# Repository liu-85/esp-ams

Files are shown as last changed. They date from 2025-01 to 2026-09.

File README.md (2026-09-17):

# YAO_AMS

**基于 YBA-AMS 改进的拓竹打印机自动换料系统（ESP32-C3 / ESP32-S3 双平台 + MicroPython）**

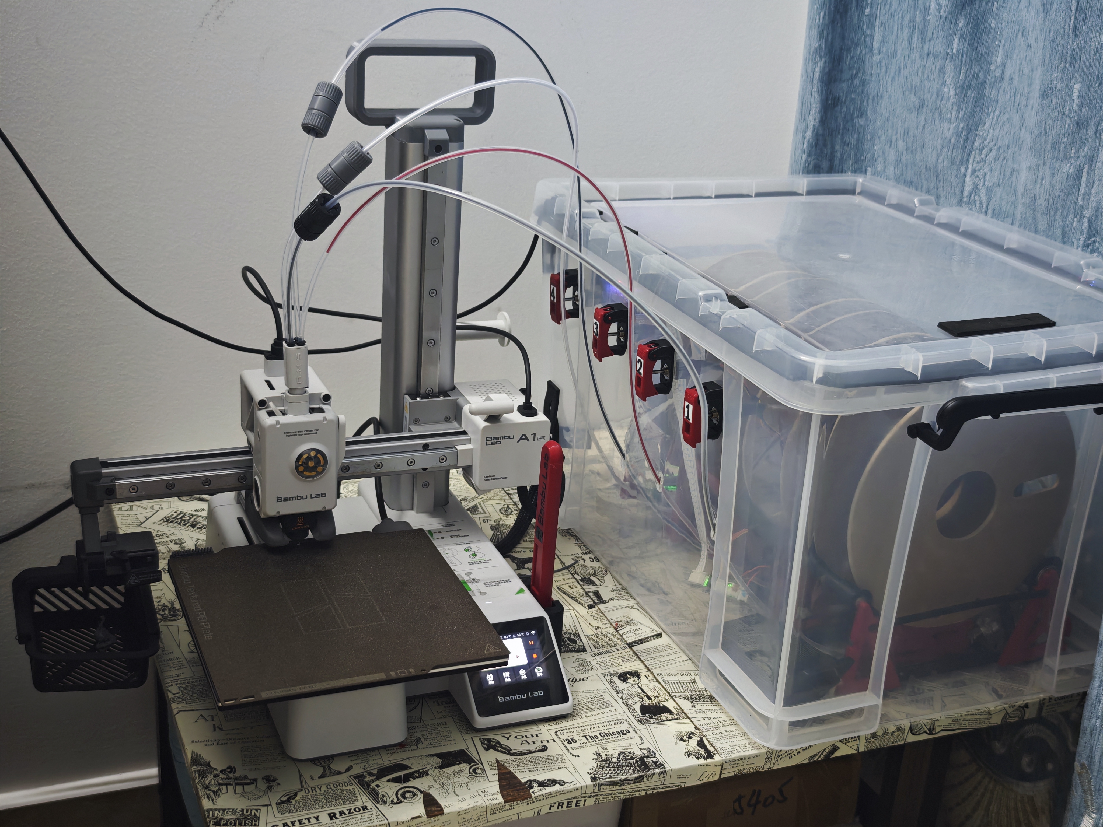
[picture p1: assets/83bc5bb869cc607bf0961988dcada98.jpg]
YAO_AMS 整机


---

## 目录

- [简介](#简介)
- [功能特性](#功能特性)
- [硬件方案](#硬件方案)
  - [1 个电机 + 4 路电磁离合](#1-个电机--4-路电磁离合)
  - [ESP32-C3 引脚约束](#esp32-c3-引脚约束)
  - [默认接线表](#默认接线表)
  - [电气注意事项](#电气注意事项)
  - [物料清单](#物料清单)
- [项目结构](#项目结构)
- [快速开始](#快速开始)
- [换料时序与软件架构](#换料时序与软件架构)
- [联网与配网](#联网与配网)
- [硬件配置项](#硬件配置项)
- [调试](#调试)
- [应用层 OTA（网页升级，不用插 USB）](#应用层-ota网页升级不用插-usb)
- [GitHub Actions 自动编译与发布](#github-actions-自动编译与发布)
- [本地开发与自测](#本地开发与自测)
- [常见问题](#常见问题)
- [附录 A：部分 MQTT 命令说明](#附录-a部分-mqtt-命令说明)
- [附录 B：G-code 参考](#附录-bg-code-参考)
- [致谢与许可](#致谢与许可)

---

## 简介

本项目是适配拓竹（Bambu Lab）打印机的 AMS 自动换料系统，基于 YBA-AMS 改进而来。

- **主控**：**ESP32-C3 或 ESP32-S3（42 针）**，使用 MicroPython 开发，两块板共用同一套代码
- **通信**：MQTT over TLS 与打印机通信；TCP + Web 页面与操作者交互
- **执行机构**：**1 个共享直流电机 + 4 路电磁离合**（见下文）
- **已验证**：A1 mini，4 通道；主板预留扩展接口，最多支持 8 通道
- **固件要求**：打印机固件版本需低于 `01.03.01.00`
- **换料速度**：约 1 分半（从停止打印到恢复打印，含冲刷时间）

> ⚠️ **与上游版本的主要差异**：上游 YBA-AMS 是「每个料盘位一个电机」，本项目
> 改为「一个共享电机 + 每通道一个电磁离合」。这带来两个变化：
> 1. GPIO 从 8 个降到 6 个，且不再使用 ESP32-C3 上不存在的 GPIO22/23；
> 2. **引入了新的安全约束：任何时刻最多只能有 1 路电磁离合吸合**，
>    软件层用四重机制强制保证（见 [换料时序与软件架构](#换料时序与软件架构)）。

> 💡 **选板建议**：**优先用 ESP32-S3（42 针）**。C3 只有 400KB SRAM，应用加载后
> 空闲堆约 60KB，传 40KB 以上的配置页面时 WiFi 驱动可能申请不到连续收发缓冲，
> 表现为「网页打不开 / 一直转圈」（加上 OTA 之后应用变大，这个问题会更明显）。
> S3 有 512KB SRAM（还可带 PSRAM），同一个应用跑起来余量充足，而且 4 路离合
> 不必再挤到 strapping 脚上。详见 [ESP32-S3（42 针）可用 IO](#esp32-s342-针可用-io)。

---

## 功能特性

| 能力 | 说明 |
| --- | --- |
| 自动换料 | 监听打印机 MQTT 状态，检测到换料请求后自动退料 + 进料，再恢复打印 |
| 多通道 | 默认 4 通道，最多 8 通道 |
| 颜色映射 | 网页上把打印机的 T 通道号映射到任意物理料盘位，可逐个设置料卷颜色，配置持久化 |
| 掉电保持 | WiFi / MQTT / 通道映射 / 颜色 / 当前料盘全部存在 `config.json`，断电重启不丢 |
| 状态指示 | 板载 LED：熄 = 未联网，闪 = WiFi 已连，常亮 = MQTT 已连 |
| 快速联网 | 首次配网成功后**不再扫描 WiFi**，开机直接用保存的账号密码直连，几十毫秒进网络 |
| 热点兜底 | 自动连接最多试 3 次，全部失败就打开热点 `AMS_WIFI`，用手机连上去重新配网 |
| 网页配置 | 响应式页面，手机 / 电脑都能用；一个 `/status` 接口拿全状态并每 2 秒自动刷新 |
| 取色器 | 通道颜色用 Windows 风格的调色板对话框：基本颜色 + HSV 渐变 + RGB/HSV 数值 + 自定义颜色 |
| 硬件调试 | 网页上实时显示 4 路离合状态与总线忙闲，并可手动点动任意通道 |
| 点动时长可调 | 硬件调试页统一设置 4 个通道的「进退响应时间」（0.2 ~ 60 秒），按一下转多久就转多久，存进设备重启不丢；**只影响手动点动，不碰自动换料** |
| 点动不卡页面 | 手动点动是「**立刻回包 + 后台计时**」：按下瞬间就开始动作并回响应，网页不转圈；动作期间再按会被明确拒绝（不排队） |
| 应用层 OTA | 网页上传 `.ams` 更新包，设备把程序与页面写进自己的文件系统后自动重启，**不用插 USB、不用重新配网**；整机固件 BIN 会被识别出来并提示改走 USB |
| 电磁离合互斥 | 软件层强制同一时刻最多 1 路吸合，含启动检查 / 吸合前复核 / 运行期体检 |
| 一键烧录 | 一个 `.bin` 覆盖整片 Flash（引导程序 + 分区表 + MicroPython + 全部代码 + umqtt 库），烧完直接上电即用 |
| CI 自动构建 | 每次提交自动编译：语法检查 + 自测 + 单文件固件 + `.mpy` 包；主分支更新 `latest` 预发布版，打 tag 发正式 Release |

---

## 硬件方案

### 1 个电机 + 4 路电磁离合

```
                        ┌── 电磁离合 1 ──> 料盘位 1 送料轮
                        ├── 电磁离合 2 ──> 料盘位 2 送料轮
   共享直流电机 ────────┤
   (H 桥 IN1 / IN2)     ├── 电磁离合 3 ──> 料盘位 3 送料轮
                        └── 电磁离合 4 ──> 料盘位 4 送料轮

   动作：需要哪个料盘位送料，就吸合那一路离合，让它的送料轮咬上电机主轴，
        然后电机正转（进料）或反转（退料），动作完成后立刻断开离合。
```

**为什么必须保证只有 1 路吸合？** 如果有 2 路同时吸合，电机会同时拖动两个
料盘位的送料轮，两卷料互相拉扯，结果是断料、打滑或打印机报错。除了机械损坏，
4 路线圈同时吸合的浪涌电流也容易把 5V 电源拉塌，导致主控复位。

软件层的保证机制（`python_code/motor_clutch.py`）：

1. **物理层前置断开** —— 任何一次吸合之前，都先无条件下发「全部断开」电平
2. **吸合前状态复核** —— 写完全部断开后回读每一路，发现残留就再次断开并取消本次动作
3. **直接调用拦截** —— `Clutch` 的引脚只能由总线改写，绕过总线调用会抛异常
4. **运行期体检** —— 主循环每个周期调用 `assert_single()`，发现多路吸合立即全部断开

这四条都有对应的自动化测试覆盖，见 [本地开发与自测](#本地开发与自测)。

### ESP32-C3 引脚约束

ESP32-C3 只有 `GPIO0 ~ GPIO21`，其中相当一部分不能当普通 IO 用：

| GPIO | 用途 | 能否使用 |
| --- | --- | --- |
| `GPIO2` / `GPIO3` / `GPIO8` / `GPIO9` | **strapping 启动模式脚**，上电瞬间电平决定从哪启动（GPIO9 = BOOT 键） | ⛔ **绝不能做输出** |
| `GPIO11` ~ `GPIO17` | 模组内置 SPI Flash（含 VDD_SPI） | **不可用** |
| `GPIO18` / `GPIO19` | USB D- / D+ | 接了 USB 座就不能用 |
| `GPIO20` / `GPIO21` | UART0 RX / TX，默认日志与 REPL 口 | 不建议用 |
| `GPIO4` ~ `GPIO7` | JTAG 调试口 | 可以用，代价是放弃 JTAG |

因此可以安全当**输出**的引脚只有这 7 只：
**GPIO0、GPIO1、GPIO4、GPIO5、GPIO6、GPIO7、GPIO10**。

> ⚠️ **GPIO2 和 GPIO3 不是「空脚」，是启动模式选择脚。**
>
> 依据《ESP32-C3 技术参考手册》第 7 章表 7.2-1：复位释放后由
> **GPIO2、GPIO3、GPIO8、GPIO9 共同控制 Boot 模式**。
> 而且 datasheet 表 4-1 写得很明确：GPIO2、GPIO8 复位后是**浮空**，
> 这四个脚里只有 GPIO9 带内部弱上拉。
>
> 把电机 H 桥的 IN1/IN2 接到 GPIO2 / GPIO3 上，AT8236 输入级的
> **内置下拉电阻**会把这两个脚在上电瞬间拉低，芯片就进不了正常启动模式 ——
> 现象正是**反复重启、Wi-Fi 能连但网页打不开、电机一直有电流声**。
> （另有一条更直接的：GPIO2 上还挂着 1kHz 的状态灯 PWM，
> IN1 也接在 GPIO2 的话，电机就变成「跟着呼吸灯闪」。）
>
> `hardware_config.validate()` 已经把「电机接在 strapping 脚上」列为**硬错误**，
> 上电能直接在串口日志和网页的「上电诊断」里看到。

> 📌 上游代码里的 **GPIO22 / GPIO23 是经典 ESP32（38 脚）的编号，ESP32-C3 上不存在**，
> 必须改掉。本项目已全部重排。

### ESP32-S3（42 针）可用 IO

ESP32-S3 的 GPIO 多得多，本项目在 S3 上的默认接线**全部落在干净脚上**，
不再有 C3 那种「4 号离合挤在 strapping 脚上」的将就。

引脚性质一览（以 42 针模组排针为准）：

| GPIO | 状态 | 说明 |
| --- | --- | --- |
| `GPIO0` | ⚠️ strapping | BOOT 键；作**输入**安全，作输出会把上电电平改掉 |
| `GPIO1` | ✅ 空闲 | ADC1_CH0 |
| `GPIO2` | 状态 LED | 板载灯（本方案用作状态灯） |
| `GPIO3` | ⚠️ strapping | JTAG 信号源选择；作输入安全 |
| `GPIO4` / `GPIO5` | 电机 | H 桥 IN1 / IN2 |
| `GPIO6` ~ `GPIO9` | 电磁离合 1~4 | ★ 四只全是干净脚 |
| `GPIO10` | ✅ 空闲 | |
| `GPIO11` ~ `GPIO18` | ✅ 空闲 | `11~14` 推荐给到位开关（排针集中） |
| `GPIO19` / `GPIO20` | ❌ USB | USB D- / D+，用掉就没法用 USB 串口 |
| `GPIO21` | ✅ 空闲 | |
| `GPIO22` ~ `GPIO25` | — | 该封装不引出 |
| `GPIO26` ~ `GPIO32` | ❌ Flash | 模组内置 SPI Flash（SPI0/1） |
| `GPIO33` ~ `GPIO37` | ❌ PSRAM | 八线 PSRAM 占用（N8R8 / N16R8）；无 PSRAM 的模组上可用 |
| `GPIO38` | ✅ 空闲 | |
| `GPIO39` ~ `GPIO42` | ✅ 空闲 | 默认是 JTAG（MTCK/MTDO/MTDI/MTMS），当普通 IO 就没在线调试了 |
| `GPIO43` / `GPIO44` | ❌ UART | UART0 TX / RX（REPL 与日志口） |
| `GPIO45` | ⚠️ strapping | VDD_SPI 电压选择；作输入安全 |
| `GPIO46` | ⚠️ strapping | ROM 打印 / 启动；作输入安全 |
| `GPIO47` / `GPIO48` | ✅ 空闲 | 48 在官方 DevKitC-1 上是板载 RGB 灯 |

**★ 剩余可用 IO 全部引出（本方案用掉 6 只 + 1 只状态灯之后）：**

| 类别 | 引脚 | 数量 |
| --- | --- | --- |
| 干净可用脚 | `GPIO1`、`GPIO10`、`GPIO11`、`GPIO12`、`GPIO13`、`GPIO14`、`GPIO15`、`GPIO16`、`GPIO17`、`GPIO18`、`GPIO21`、`GPIO38`、`GPIO39`、`GPIO40`、`GPIO41`、`GPIO42`、`GPIO47`、`GPIO48` | **18** |
| 空闲 strapping 脚 | `GPIO0`、`GPIO3`、`GPIO45`、`GPIO46` | 4 |

其中 `GPIO11 ~ GPIO14` 是到位开关的推荐脚；若装上 4 路到位开关占用它们，
干净可用脚还剩 14 只。这 18 只干净脚**全部**在
[`python_code/board_s3.py`](./python_code/board_s3.py) 的 `SPARE_PINS` 里列着，
上电自检和构建出的 `部署说明.txt` 也会把它们打出来（`hardware_config.SPARE_PINS`）。

```python
# 在设备 REPL 里确认剩余可用 IO
from hardware_config import SPARE_PINS, STRAPPING_SPARE_PINS, describe
print(describe())
```

### 默认接线表（两块板）

**ESP32-C3**（干净输出脚只有 7 只，刚好用完，属于将就方案）：

| 信号 | GPIO | 说明 |
| --- | --- | --- |
| 电机 H 桥 IN1 | `GPIO4` | 方向 `1` = 进料（正转） |
| 电机 H 桥 IN2 | `GPIO5` | 方向 `-1` = 退料（反转） |
| 电磁离合 1 | `GPIO6` | 料盘位 1 |
| 电磁离合 2 | `GPIO7` | 料盘位 2 |
| 电磁离合 3 | `GPIO10` | 料盘位 3 |
| 电磁离合 4 | `GPIO3` | 料盘位 4（⚠️ strapping 脚，能跑但建议改到 `GPIO1`） |
| 状态 LED | `GPIO2` | 板载蓝灯（⚠️ strapping 脚；设成 `None` 可彻底关掉） |
| 到位开关 1~4 | *未安装* | 预留，见下方说明；推荐 `GPIO0 / GPIO1 / GPIO8 / GPIO9` |

**ESP32-S3（42 针）**（推荐，离合全在干净脚上）：

| 信号 | GPIO | 说明 |
| --- | --- | --- |
| 电机 H 桥 IN1 | `GPIO4` | 方向 `1` = 进料（正转） |
| 电机 H 桥 IN2 | `GPIO5` | 方向 `-1` = 退料（反转） |
| 电磁离合 1 | `GPIO6` | 料盘位 1 |
| 电磁离合 2 | `GPIO7` | 料盘位 2 |
| 电磁离合 3 | `GPIO8` | 料盘位 3 |
| 电磁离合 4 | `GPIO9` | 料盘位 4（✅ 干净脚，不再是 strapping） |
| 状态 LED | `GPIO2` | 板载灯（设成 `None` 可彻底关掉） |
| 到位开关 1~4 | *未安装* | 预留，见下方说明；推荐 `GPIO11 / GPIO12 / GPIO13 / GPIO14` |

> 两块板的电机与离合 1~3 引脚号**故意保持一致**，这样换板子时接线基本不用动，
> 唯一变化是 C3 的离合 4 在 `GPIO3`、S3 的离合 4 在 `GPIO9`。

### 两块板怎么共用一套代码

执行机构、时序、业务逻辑两块板**完全一样**，不同的只有「这块芯片哪些脚能用」。
所以引脚差异被拆成两份独立文件，业务代码一行都不用改：

| 文件 | 作用 | 要不要提交 |
| --- | --- | --- |
| [`python_code/board_c3.py`](./python_code/board_c3.py) | C3 的引脚表 / 保留脚 / strapping / 剩余可用 IO | ✅ 是源码 |
| [`python_code/board_s3.py`](./python_code/board_s3.py) | S3（42 针）同上，另外列出全部剩余可用 IO | ✅ 是源码 |
| [`python_code/hardware_config.py`](./python_code/hardware_config.py) | **唯一硬件配置入口**：选板型 + 业务参数 + 上电自检 | ✅ 是源码 |
| `board_select.py` | 由编译脚本生成，内容就一行 `BOARD = "c3" / "s3" / "auto"` | ❌ 构建产物，别手改 |
| `board_override.py` | 可选，放在板子上即可覆盖任意引脚，不用改仓库代码 | ❌ 现场文件 |

**板型是怎么定下来的（优先级从高到低）：**

1. **编译时写死的 `board_select.py`** —— `tools/build_mpy.py --board s3` 或
   `tools/make_firmware_bin.py --board s3` 会往包里写 `BOARD = "s3"`。
   也就是说 **CI 打出来的两个固件各自「天生」用对配置**，不依赖运行时识别。
2. **现场覆盖 `board_override.py`** —— 手上这块板接线和别人不一样时用，例如
   ```python
   # 板子上放这么一个文件即可，重启生效
   CLUTCH_PINS = (6, 7, 10, 1)
   LED_PIN = None
   ```
3. **自动识别 `os.uname().machine`** —— 认得出就用对应的表；认不出来按 C3 处理，
   并在自检日志里提示一句。

上层代码（`motor_clutch` / `device_processing` / `reset_info` …）只写
`from hardware_config import MOTOR_PIN_IN1`，所以换板子/换引脚不会波及业务逻辑。

**编译两个开发板：**

```bash
python tools/build_mpy.py                 # 默认 --board both：C3 与 S3 各出一个包
python tools/build_mpy.py --board c3      # 只编 C3 → dist/c3/
python tools/build_mpy.py --board s3      # 只编 S3 → dist/s3/
python tools/build_mpy.py --board auto    # 一份通用包，设备上按芯片自动识别

# 单文件固件（两块板各自的官方固件不同，必须分开构建）
python tools/make_firmware_bin.py --board c3 --firmware-url <C3 固件> --out dist/esp32c3-ams-firmware.bin
python tools/make_firmware_bin.py --board s3 --firmware-url <S3 固件> --out dist/esp32s3-ams-firmware.bin
```

每个构建产物里都会带一份 `board_select.py` 和一份 `部署说明.txt`，
说明里直接写出「这块板实际用哪些脚、还剩哪些脚」，不用回去翻文档。

改接线只需要改 `python_code/board_c3.py` 或 `python_code/board_s3.py` 里的一组常量，
或者用 `hardware_config.py` 里与芯片无关的业务参数，不用动业务代码。

**关于状态 LED 用 GPIO2**：板载 LED 在低电平时不导通、呈高阻，对 strapping
影响很小，所以 LED 挂在 GPIO2 上是可以接受的。但它**绝不能和任何功率器件
共用 GPIO2** —— 1kHz 的 LED PWM 会把 H 桥当灯闪。不想用状态灯就把
`hardware_config.py` 里的 `LED_PIN` 设成 `None`，代码会自动跳过。

**关于电磁离合 4 用 GPIO3**：ULN2803 的输入是达林顿基极，需要约 1.4V 才导通，
空闲时接近高阻，等于把引脚「悬空」，而 GPIO3 的官方默认状态本来就是浮空，
所以现在这样能用。但这属于**带病运行** —— 一旦换用输入带下拉的驱动板就会
起不来。建议尽早把 `CLUTCH_PINS` 改成 `(6, 7, 10, 1)`。

**关于到位开关（限位/微动开关）**：当前**未安装**，程序自动进入降级模式。
它的作用是探测「当前正在用哪个料盘」和判断「料有没有真的推动」。装了开关后，
把引脚填进 `hardware_config.py` 的 `LIMIT_SWITCH_PINS` 即可自动启用探测逻辑。

推荐接法（开关一端接 GPIO、另一端接 GND，内部上拉，低电平触发）：

- **ESP32-S3**：直接用 `GPIO11 / GPIO12 / GPIO13 / GPIO14`，
  即 `board_s3.py` 里的 `RECOMMENDED_LIMIT_SWITCH_PINS`（全干净、排针集中）
- **ESP32-C3**：通道 1 / 2 用 `GPIO0`、`GPIO1`（最干净），
  通道 3 / 4 可用 `GPIO2`、`GPIO3`、`GPIO8` 或 `GPIO9` —— 这四个是 strapping 脚，
  但「内部上拉 + 开关对地」的接法空闲时正好是高电平，符合 strapping 要求，
  作**输入**是安全的（作输出就危险了，见上）

### 电气注意事项

> ⚠️ **这两条不做大概率会烧板子，请务必看完。**

1. **电磁离合线圈必须反向并联续流二极管**（1N4148 / 1N5819 均可）。
   线圈是感性负载，断开瞬间会产生几十伏的反电动势，会击穿 GPIO 或驱动管。
2. **不要用 GPIO 直接驱动离合线圈**。GPIO 输出只有 20mA 左右，离合线圈通常
   需要 100mA 以上。中间必须加三极管（S8050 / 2N2222）、MOS 管
   （AO3400 / IRLZ44N）或光耦隔离的驱动板；三极管方案基极要串 1kΩ 电阻。

另外：4 路离合的供电建议单独走一路 5V，不要和 ESP32-C3 共用同一根细线。

3. **电机驱动的 VM 必须单独供电，且和 ESP32 共地到同一点。**
   AT8236 的 VM 是 5.5V~36V 的功率电源，不要从开发板的 5V 引脚取电。
   电机启动瞬间的浪涌电流很容易把 3.3V 拉塌，而 ESP32-C3 一旦欠压就会复位 ——
   表现就是「空载时好好的，一接上负载就一直重启」。
4. **AT8236 的 ISEN 要接检流电阻或直接接地**，VREF 决定峰值限流。
   如果限流设得太小（比如 `VREF=2.0V / RISEN=0.2Ω` → 只有 1A），
   电机带载时会「堵转式」地嗡嗡响却转不起来 —— 这也是「有电流声但没启动」的
   常见原因之一。先把 `IN1/IN2` 接好、限流放宽，再逐步收紧。

### 物料清单

| 部件 | 数量 | 备注 |
| --- | --- | --- |
| ESP32-C3 开发板 | 1 | 任意 C3 模组板均可 |
| 直流减速电机 | 1 | 带动共享主轴 |
| 电磁离合器 | 4 | 每个料盘位一个 |
| H 桥驱动模块 | 1 | 如 L9110 / DRV8833 / TB6612 |
| 续流二极管 | 4 | 1N4148 / 1N5819 |
| 三极管或 MOS 管 | 4 | 驱动离合线圈，或直接用 4 路继电器/光耦模块 |
| 到位微动开关（可选） | 0~4 | 现在没有也能跑，见降级模式说明 |
| 3D 打印件 | — | 见 [`打印件/`](./打印件) 目录 |

---

## 项目结构

```
yaoams/
├── python_code/                  # ★ 要上传到开发板的全部代码（C3 / S3 通用）
│   ├── main.py                   # 上电自动启动入口（保持 .py，不能编译成 .mpy）
│   ├── boot.py                   # 上电最先跑：置安全电平 + 记复位原因 + 累加启动计数
│   ├── reset_info.py             # ★ 复位诊断：欠压 / 看门狗 / 冷启动，网页可见
│   ├── ota_update.py             # ★ 应用层 OTA 核心：流式解析 .ams 更新包 + CRC32 校验 + 原子改名
│   ├── AMS_WEB.py                # Web 配置服务 + 任务调度入口（继承 AMS）
│   ├── AMS_MODEL.py              # ★ 换料业务逻辑：探测料盘 / 退料 / 进料 / MQTT 调度
│   ├── device_processing.py      # ★ 硬件驱动：料盘位对象(material)、电机/离合总线工厂
│   ├── motor_clutch.py           # ★ 共享电机 + 电磁离合驱动层（互斥约束在这里强制）
│   ├── hardware_config.py        # ★ 唯一的硬件配置入口：引脚、时序、降级参数
│   ├── network_model.py          # WiFi 连接管理（AP / STA）
│   ├── info_load.py              # 配置文件读写（wifi.dat / config.json）
│   ├── logout.py                 # 日志输出（串口 + 内存环形缓冲，供网页日志面板读）
│   ├── index.html                # Web 配置页面（左侧菜单 + 硬件调试 + 设备日志）
│   ├── umqtt/                    # MQTT 客户端库（第三方，纳入仓库以保证烧录后自包含）
│   │   └── simple.py             #   来自 micropython-lib（MIT）
│   └── bambu/                    # 与拓竹打印机 MQTT 通信相关
│       ├── bambu_mqtt.py         # MQTT 客户端封装（连接、订阅、发布）
│       ├── bambu_commands.py     # 常用 MQTT 命令（resume / pushall ...）
│       ├── bambu_const.py        # 打印机状态码、HMS 错误码中英对照
│       ├── bambu_G_code.py       # 常用 G-code 片段（擦拭、切料、调温）
│       └── get_event_info.py     # 从推送报文里解析换料 / 状态 / 报错信息
├── tests/                        # ★ 桌面端自测（PC / CI 运行，不烧进板子）
│   ├── run_tests.py              # 测试入口：python tests/run_tests.py
│   └── mpy_stubs/                # machine / network / ujson / uasyncio / umqtt 桩模块
├── tools/
│   ├── make_firmware_bin.py      # ★ 合成「单文件可烧录固件」（官方固件 + 本项目代码），--board 选板型
│   ├── make_update_pack.py       # ★ 把 python_code/ 打成 .ams 应用更新包（网页 OTA 用）
│   ├── lfs_mkfs.c                # ★ 生成 / 校验文件系统镜像（littlefs 2.8，与固件内置同源）
│   ├── build_mpy.py              # 交叉编译 .mpy 并打包部署 zip，--board both 时两块板各出一个
│   └── preview_server.py         # 网页本地预览服务（假数据补全接口，PC 上调页面用）
├── .github/workflows/build.yml   # ★ GitHub Actions：检查 + 自测 + 固件 + .mpy + 发布
├── g_code/                       # Bambu Studio 换料 G-code（要粘贴到切片软件）
├── 打印件/                        # 结构件 STL / 3MF
├── assets/                       # 文档图片
├── dist/                         # 构建产物（已忽略，不进版本库）
├── .gitignore
├── LICENSE
└── README.md
```

---

## 快速开始

### 第 1 步：烧录（推荐：一个文件搞定）

到本仓库的 **Releases** 页面**按你手上的开发板**下载对应的固件
（每次提交都会自动重新构建，标题为「最新构建」的那份永远是最新的）：

| 开发板 | 单文件固件 | .mpy 部署包 |
| --- | --- | --- |
| ESP32-C3 | `esp32c3-ams-firmware.bin`（4MB） | `esp32c3-ams-mpy.zip` |
| ESP32-S3（42 针） | `esp32s3-ams-firmware.bin`（8MB） | `esp32s3-ams-mpy.zip` |

```bash
pip install esptool

# ESP32-C3
esptool.py --chip esp32c3 --port COM5 write_flash -z 0x0 esp32c3-ams-firmware.bin

# ESP32-S3（42 针，需 8MB 及以上 Flash）
esptool.py --chip esp32s3 --port COM5 write_flash -z 0x0 esp32s3-ams-firmware.bin
```

就这一条命令。文件里已经按你的板型写好了 `board_select.py`，
**板子一上电就知道该加载哪份引脚表**，不需要任何手工选择。

C3 固件从地址 `0x0` 开始覆盖**整片 4MB Flash**：

| 地址 | 内容 |
| --- | --- |
| `0x000000` | ESP32-C3 引导程序 |
| `0x008000` | 分区表（nvs / phy_init / app / vfs） |
| `0x010000` | MicroPython v1.23.0（官方发布的固件，未做修改） |
| `0x200000` | 文件系统（littlefs，2MB），放着 `python_code/` 的全部代码 + `umqtt` 库 |

S3 固件布局相同，只是 vfs 分区更大（`0x200000` 起、6MB），
所以整片总长 8MB —— 官方 S3 固件本身就是按 8MB Flash 布局的，
**4MB Flash 的 S3 模组请改用 `.mpy` 部署包**（或自行改小分区表）。

也就是说：**不用先烧固件、也不用再上传任何 .py**，烧完直接上电就能跑，
下面第 2 步可以跳过，直接看第 3 步。

> 正常情况下不需要先 `erase_flash` —— 这个文件覆盖整片 Flash，旧文件系统区域会被
> 整体重写。只有在出现异常（之前烧过别的固件、或想彻底清空）时才先补一条
> `esptool.py --chip <你的芯片> --port COM5 erase_flash`，然后再烧。

### 第 2 步（备选）：自己烧固件 + 上传代码

需要频繁改代码调试、或者不想整片重烧时，用这种方式。

先烧官方 MicroPython 固件（C3 用 `ESP32_GENERIC_C3`，S3 用 `ESP32_GENERIC_S3`）：

```bash
# ESP32-C3
esptool.py --chip esp32c3 --port COM5 erase_flash
esptool.py --chip esp32c3 --port COM5 write_flash -z 0x0 ESP32_GENERIC_C3-xxxx.bin

# ESP32-S3（42 针）
esptool.py --chip esp32s3 --port COM5 erase_flash
esptool.py --chip esp32s3 --port COM5 write_flash -z 0x0 ESP32_GENERIC_S3-xxxx.bin
```

固件分别到
[micropython.org/download/ESP32_GENERIC_C3](https://micropython.org/download/ESP32_GENERIC_C3/)
与
[micropython.org/download/ESP32_GENERIC_S3](https://micropython.org/download/ESP32_GENERIC_S3/)
下载。记住版本号（例如 `v1.23.0`），CI 与 `.mpy` 都要和它对齐。

然后用 `mpremote` 上传代码：

```bash
pip install mpremote

# Windows
mpremote connect COM5 fs cp -r ./python_code/ :
# Linux / macOS
mpremote connect /dev/ttyACM0 fs cp -r ./python_code/ :
```

也可以直接用 Thonny 把 `python_code/` 里的文件拖到设备根目录（注意 `bambu/`
和 `umqtt/` 要建成同名子目录）。

或者用 CI 编译好的 `.mpy` 包（体积更小、启动更快）：

```bash
# 1) 从 GitHub Actions 下载对应板型的构件，或本地编译（默认两块板都编）
pip install mpy-cross==1.23.0
python tools/build_mpy.py                      # → dist/c3/ 与 dist/s3/
python tools/build_mpy.py --board s3           # 只编 S3 → dist/s3/

# 2) 解压后把**对应板型那个目录**整体上传
mpremote connect COM5 fs cp -r ./dist/s3/ :
```

> ⚠️ `mpy-cross` 的版本必须和板子上的固件版本一致，否则设备会报
> `ValueError: incompatible .mpy file`。
>
> ⚠️ 上传 `.mpy` 包时**务必选对板型目录**（`dist/c3/` 还是 `dist/s3/`）——
> 包里的 `board_select.py` 决定了设备加载哪份引脚表。传错了不会烧板子
> （上电自检会报引脚错误并拒绝启用硬件），但网页会不对劲。
>
> 注意 `boot.py` / `main.py` 必须是源码 `.py`（MicroPython 是直接执行这两个文件，
> 它们被编译成 `.mpy` 后不会被执行）。

### 第 3 步：修改 Bambu Studio 的换料 G-code

Bambu Studio → 打印机设置 → 机器 G-code → **Change filament G-code**，
把内容替换成 [`g_code/`](./g_code) 目录里的版本（二选一）：

- `切换耗材g_code.txt` —— 基础版
- `切换耗材（减少冲刷次数和加强切刀版本）.txt` —— 冲刷更少、切料更彻底（推荐）

关键点是里面必须有这一行，AMS 靠它知道「该换料了」：

```gcode
M73 P101 R[next_extruder]
M400 U1
```

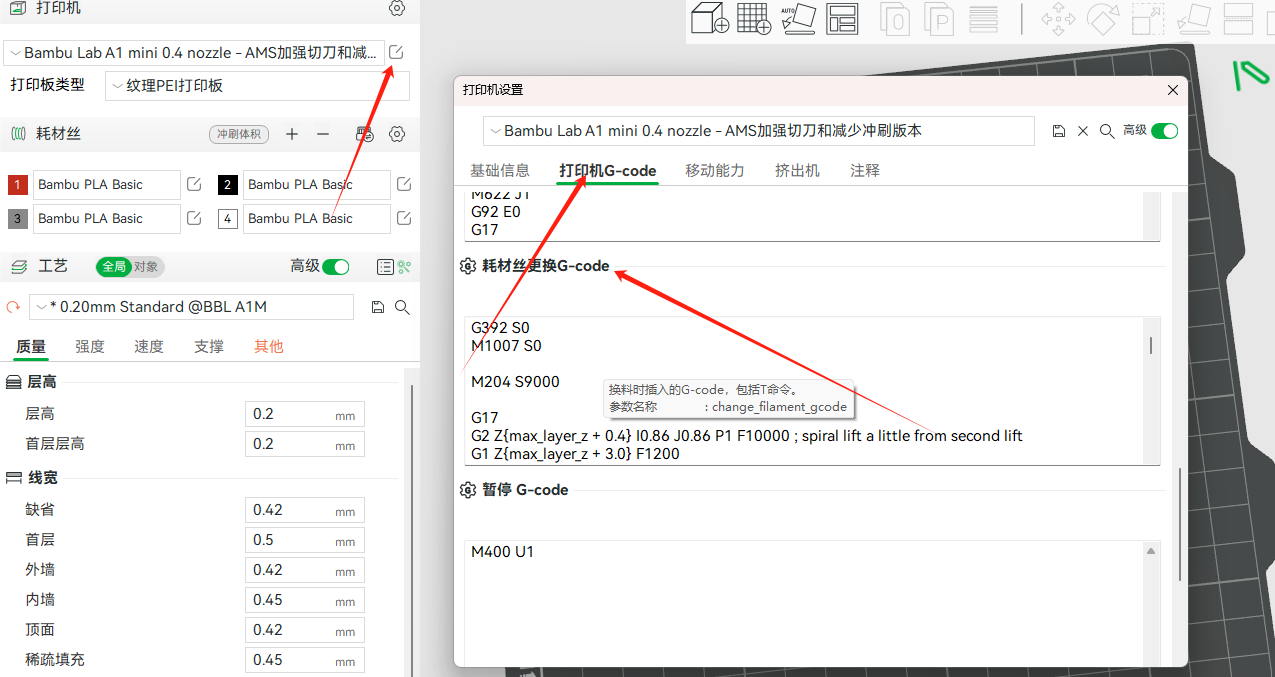
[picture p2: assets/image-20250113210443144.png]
修改换料 G-code


### 第 4 步：首次配置

1. 给主板上电。如果还没配过 WiFi（或连接失败 3 次），它会自动开启热点
   **`AMS_WIFI`**，密码 **`A12345678`**
2. 电脑 / 手机连上该热点，浏览器打开 `192.168.4.1`
3. **WiFi 配置**：在列表里选你的 WiFi（只能选 **2.4G** 频段的）并填密码 → 点「连接这个 WiFi」
   （必须在和打印机同一个网络下）
4. 连上后会显示主板分配到的新 IP，**记下它**，之后都用这个 IP 访问。
   页面会自动记住账号密码，以后开机会直接连，不再重新扫描；
   同时会自动关掉配置热点 —— **左侧菜单里的「WiFi 配置」也会跟着消失**（这是故意的）
5. **打印机 MQTT 配置**：填入打印机的 IP、序列号、访问码（8 位）、MQTT 端口等 →
   点「保存并连接」。**这一步一定会把配置存进设备**，即使当时连不上打印机也会存，
   提示里会写清楚是「已保存并连上」还是「已保存但暂时连不上」
6. **打印机通道设置**：默认就是 **4 个通道**。把「料盘 1~4」映射到打印机要用的通道号，
   点色块可以给每个料卷设颜色 —— 会弹出一个类似 Windows「颜色」对话框的取色器：
   左边是基本颜色和自定义颜色，右边是 HSV 渐变区 + 色相条，也可以用 RGB / HSV
   数值精确指定 → 点「保存通道与颜色」

### 页面长什么样

页面分成左右两半：

```
┌──────────────┬──────────────────────────────────────────────┐
│ YAO AMS      │  ● WiFi      ● MQTT                          │
├──────────────┼──────────────────────────────────────────────┤
│ ▸ 网络       │                                              │
│ ▸ 打印       │     选中目录里的页面（运行状态 / 上电诊断 /   │
│ ▾ 系统       │     打印机 MQTT / 通道设置 / 硬件调试 /       │
│    运行状态  │     系统升级 OTA）                            │
│    上电诊断  │                                              │
│    系统升级  ├──────────────────────────────────────────────┤
│              │  设备日志       空闲内存 18.0 KB  清屏  折叠  │
│              │  00:00.412 Web 服务已启动，监听 0.0.0.0:80   │
│              │  00:01.204 WiFi 连接成功: xxx  IP=…          │
└──────────────┴──────────────────────────────────────────────┘
```

- **左侧是菜单**，每个目录默认折叠，点标题展开；展开状态记在浏览器里，刷新不会变
- **右侧上方是内容**，一次只显示一个页面
- **右侧下方常驻「设备日志」**，每 2 秒刷新一次，不用再插 USB 看串口。
  带 ★ 的报错行会标红，点「折叠」可以收起来
- **「WiFi 配置」只在配置热点开启时出现**。连上网之后它就藏起来了。
  想换 WiFi 就到「运行状态」点「打开配置热点」，手机连上 `AMS_WIFI` 再配一次
- **「系统 → 系统升级 (OTA)」** 用来上传 `.ams` 更新包（见 [应用层 OTA](#应用层-ota网页升级不用插-usb)）
- 手机上左侧菜单收成一个「☰」抽屉按钮，布局不变

> 页面每 2 秒自动刷新状态和日志，不用手动按 F5。
> WiFi 列表在打开「WiFi 配置」页面时才扫描（扫描本身要 1~2 秒），想重新扫点「重新扫描」。

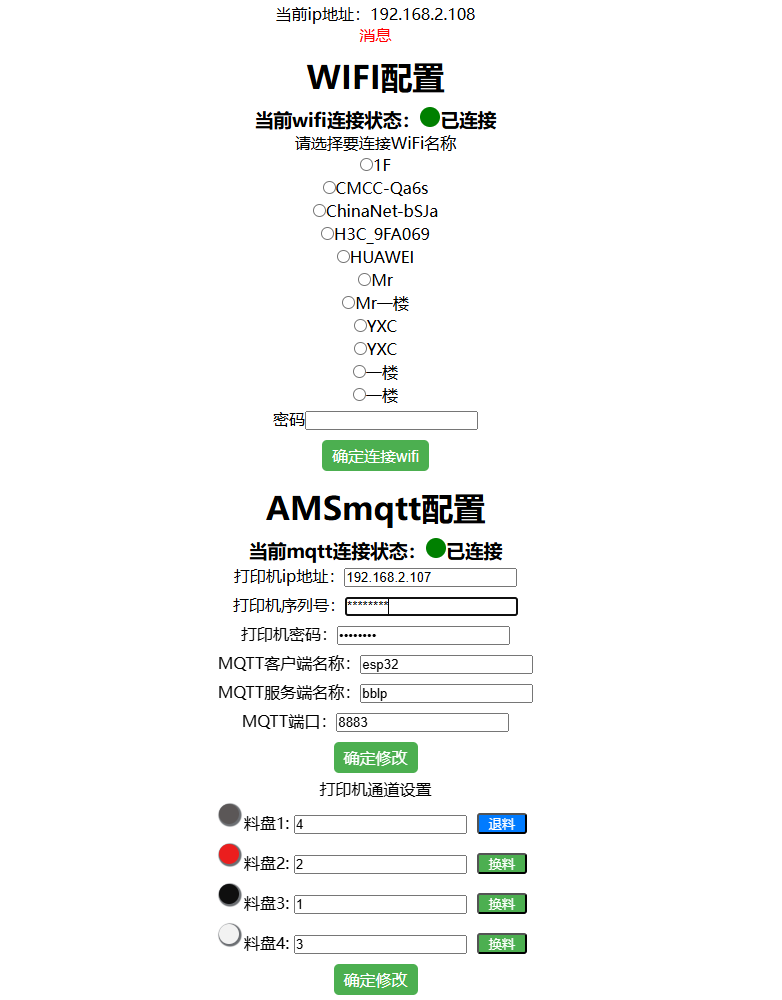
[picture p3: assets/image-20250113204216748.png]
初次配置页面


### 第 5 步：开始打印

1. 确认板载 LED **常亮**（= MQTT 已连接）。闪烁表示只连上了 WiFi。
2. 在切片软件里把耗材映射到对应通道：

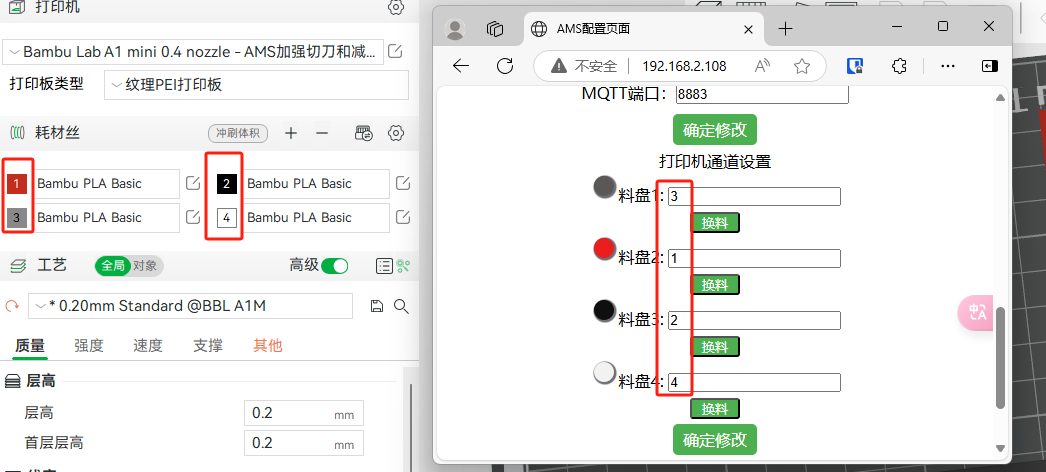
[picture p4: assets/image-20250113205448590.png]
通道映射
   

3. 开始打印。打印机暂停并请求换料时，AMS 会自动完成换料并恢复打印。

---

## 换料时序与软件架构

### 分层结构

```
        ┌─────────────────────────────────────────────┐
        │  AMS_WEB.py     Web 配置 + asyncio 任务调度   │
        ├─────────────────────────────────────────────┤
        │  AMS_MODEL.py   换料业务逻辑（时序编排）      │
        │    now_filament / fileament_move             │
        │    exchange_fileament                        │
        ├─────────────────────────────────────────────┤
        │  device_processing.py                        │
        │    material（料盘位门面）                     │
        ├─────────────────────────────────────────────┤
        │  motor_clutch.py                             │
        │    FilamentMotorBus ★ 离合互斥仲裁            │
        │    HBridgeMotor / Clutch / LimitSwitch       │
        ├─────────────────────────────────────────────┤
        │  hardware_config.py   选板型 + 时序 + 降级参数 │
        │  board_c3.py / board_s3.py  两块板的引脚表     │
        └─────────────────────────────────────────────┘
```

### 一次换料的完整时序

```
打印机                           ESP32-C3 (AMS)
  │                                   │
  │ 暂停 + 换料 G-code                  │
  │ M73 P101 R[next_extruder]         │
  │ M400 U1                           │
  ├────────── MQTT 推送 ─────────────>│  get_is_change_ams() 识别到换料请求
  │                                   │
  │<───────── 发 M83（相对挤出）────────┤
  │                                   │
  │<───────── 发 G1 E-50 F200 ─────────┤  打印机把喷嘴里的料退出来
  │                                   │
  │                                   │  ① 吸合【旧】通道离合
  │                                   │     电机反转 → 把料收进缓冲区
  │                                   │     停电机 → 断开全部离合
  │                                   │
  │                                   │  ② 吸合【新】通道离合
  │                                   │     电机正转 → 把新料推向挤出机
  │                                   │     停电机 → 断开全部离合
  │                                   │
  │<───────── 发 G1 E50 F200 ─────────┤  打印机把料拉进喷嘴
  │                                   │     同时 AMS 辅助推料 1s
  │                                   │
  │                                   │  ③ 更新 filament_current 并写入 config.json
  │                                   │
  │<───────── 发 resume ──────────────┤
  │ 继续打印                           │
```

### 关键实现细节

**离合互斥**：所有「吸合 → 动作 → 断开」的复合操作都走 `bus.run()` 或
`bus.hold()`，两者都用 `try/finally` 保证即使中途抛异常也一定停电机、
断开全部离合。主循环里每 200ms 还会做一次 `assert_single()` 体检。

**降级模式（未安装到位开关时）**：这是当前的实际运行模式，有两点要注意：

- 无法探测「当前在用哪个料盘」，程序直接沿用 `config.json` 里记录的
  `filament_current`。**所以这种情况下不要手动插拔料盘**，否则记录会和实际不一致。
- 送料/退料改为按时间推进，时长由 `NO_LIMIT_LOAD_MS` /
  `NO_LIMIT_RETRACT_MS` 决定。这两个值**必须按实机实测调整**：
  太小 → 料没送到挤出机，打印机会报「耗材缺失」；
  太大 → 料被顶弯、在缓冲区堆积，甚至顶坏挤出机。

**H 桥换向死区**：电机换向时先两脚拉低、等待 `MOTOR_DEAD_TIME_MS`，
再切换到新方向，避免 H 桥上下管直通烧驱动芯片。

---

## 联网与配网

### 上电联网：直连，不扫描

```
上电
 ├─ 读 wifi.dat（保存过的 WiFi 账号密码表）
 ├─ 有记录 → 逐个直接尝试连接（最多 3 次）
 │            └─ 成功 → 继续启动，连打印机 MQTT
 └─ 没有记录 / 3 次全失败
              └─ 打开热点 AMS_WIFI（密码 A12345678）
                 手机连上后访问 http://192.168.4.1 重新配网
```

**为什么不像以前那样先扫描？** `scan()` 是阻塞操作，在 ESP32-C3 上要 1.5~3 秒，
而且扫描时射频要切信道，会打断正在进行的连接。首次配网成功后账号密码已经存在
`wifi.dat` 里，直接连既快又稳。

只有在页面上点「重新扫描」或页面首次加载需要列出周围 WiFi 时才会真的扫描，
结果带 60 秒缓存（`SCAN_CACHE_MS`），不会每刷新一次就卡 2 秒。

### 连接成功的判定标准

必须**同时**满足：关联上 AP **且** 拿到非 `0.0.0.0` 的 IP。
只看 `isconnected()` 是不够的 —— 那时 DHCP 可能还没完成，直接去连 MQTT 必然失败。
密码错误、找不到该 AP 这类硬失败会立即返回，不会白等满超时。

### 联网相关参数

都在 `python_code/network_model.py` 顶部（与硬件引脚分开，改起来更直观）：

| 配置项 | 默认值 | 说明 |
| --- | --- | --- |
| `AP_SSID` / `AP_PASSWORD` | `AMS_WIFI` / `A12345678` | 配置热点的名称与密码（WPA2 要求密码至少 8 位） |
| `WIFI_BOOT_ATTEMPTS` | `3` | 上电自动连接的总尝试次数，用完就开热点 |
| `CONNECT_TIMEOUT_MS` | `8000` | 单次连接最长等待（含 DHCP 拿 IP） |
| `RECONNECT_GAP_MS` | `500` | 一轮试完还没成功，歇一下再试下一轮 |
| `SCAN_CACHE_MS` | `60000` | 扫描结果缓存时长 |

### 网页接口

| 方法 | 路径 | 说明 |
| --- | --- | --- |
| `GET` | `/` | 配置页面 |
| `GET` | `/status` | ★ 聚合状态：IP / WiFi / MQTT / 通道 / 颜色 / 硬件 / 复位诊断 / 内存余量，一次拿全 |
| `GET` | `/log` | ★ 设备日志（最近 24 行），给页面右下角的日志面板用 |
| `GET` | `/wifi_scan` | 强制重新扫描 WiFi（阻塞约 2 秒，仅用户点击时调用） |
| `GET` | `/boot_clear` | 把「启动次数」清零（排查复位循环时用） |
| `POST` | `/wifi_connect` | `{"name":ssid,"password":pwd}` |
| `POST` | `/mqtt_connect` | 打印机 IP / 序列号 / 访问码 / 端口等，**先落盘再连接** |
| `POST` | `/access_set` | `{"access_list":[...],"color_list":[...]}` |
| `POST` | `/hardware_test` | `{"channel":1,"direction":1}` 手动点动。**立刻回包**，动作在后台计时；`times_ms` 可选，不传就用设备上设的「进退响应时间」 |
| `POST` | `/jog_set` | `{"seconds":3}` 或 `{"ms":3000}` 设置 4 个通道统一的进退响应时间（0.2~60 秒，超范围会被夹住并如实告知） |
| `POST` | `/ota_upload` | ★ 应用层 OTA：请求体就是 `.ams` 更新包的原始字节（`Content-Type: application/octet-stream`），设备**边收边写**，全部校验通过后自动重启 |
| `POST` | `/ap_set` | `{"on":1}` 开配置热点 / `{"on":0}` 关 |

**为什么要有 `/status`**：页面上有 IP、WiFi、MQTT、通道、硬件五块状态，早期是发 5 个
请求分别取。单线程服务端只能串行处理，累计延迟很明显。现在合成 1 个请求，
页面每 2 秒轮询一次就够了。

**为什么日志要单独开 `/log`**：日志的行数随时在变。如果塞进 `/status`，
这个每 2 秒被打一次的接口就会跟着一起变胖，最后把空闲堆吃光。
分开之后 `/status` 的体积是恒定的，好控制。

### 网页性能上的几个坑（都已修掉）

| 问题 | 旧做法 | 现在 |
| --- | --- | --- |
| 页面极慢 | `index.html` **逐行发送**，每行 `await sleep(10ms)`，400 多行要 4 秒以上 | 整份文件用 `os.stat` 取长度、带 `Content-Length` 分块流式发送 |
| **页面打不开**<br>`memory allocation failed` | 把 40KB 的页面 `f.read()` **整份读进内存**（还有一份 `.encode()` 拷贝），ESP32-C3 拿不到这么长的连续内存；而且缓存写不进去，**每个请求都在同一处再失败一次** | 每次只读 1KB（`FILE_CHUNK`）读一块发一块，单次最大分配 1KB；发送前 `gc.collect()` 收拢碎片 |
| **页面能开、但数据全是 `-`**<br>通道和硬件永远「加载中」 | `/status` 里塞了 `boot_safety.report`（一整段中文接线表），`ujson.dumps` 之后体积翻好几倍，`send_response` 再 `.encode()` 复制一份 → 板子 OOM，而这个接口每次轮询都失败 | 只返回网页真正用到的字段（`report` 不进 JSON、`problems` 截断、SSID 限 12 个）；**每个字段单独兜底**；字符串改成「切块 → 逐块 encode → 逐块发」，峰值只有 512 字符 |
| **保存提示 404 且没存进去** | 读请求时看到 `\r\n\r\n` 就返回，POST 的 JSON 请求体还在下一个 TCP 段里 → 解析出 `None` → 路由条件不成立 → 掉进 404 | 按 `Content-Length` 把请求体读完；写接口收到空请求体时回 **400 并说明原因**，不再谎报 404 |
| MQTT 配置永远存不下来 | 只有 MQTT 当场连上才写 `config.json`，而 AP 模式下根本没联网 → 必然失败 | **先落盘，再连接**；连不上只作提示，返回 `saved` / `connected` 两个字段 |
| 每个请求白等 | accept 循环里 `await sleep(500ms)` | 改成 20ms 轮询 |
| 偶尔打不开 | 读请求头用阻塞 `recv` + 3 秒超时，浏览器的空闲预连接会把服务端卡满 3 秒 | 非阻塞读 + `await` 让步，总上限 0.6 秒，等不到就丢掉连接 |
| **页面卡死**<br>「一卡几十秒，像崩溃了一样」 | `/status` 里调 `check_mqtt_connection()` → **真的在 SSL 上发 PINGREQ**。打印机连接一旦半死（拔电 / 换网 / 休眠），这个阻塞写会一直卡到 TCP 自己超时 —— **几十秒**，而 `/status` 每 2 秒被轮询一次 | `/status` 只读主循环留下的缓存标志 `mqtt_alive_cached()`，**一次网络 I/O 都不做**；真实探测仍由主循环做，但带 0.8 秒硬超时 |
| **要刷好几次才出页面** | ① `accept → 处理 → accept` 串行，一个慢连接堵住后面全部；② `listen(2)` 太小，浏览器一次开 6 个连接，多出来的 SYN 被内核丢掉，浏览器按 TCP 退避（1s→2s→4s…）重试；③ 浏览器的「预连接」套接字什么都不发，服务端却给它白等 600ms | ① 改成 3 个 worker 轮流 accept（读请求头那段是 `await` 让步的，并发是真的）；② `listen(8)`；③ 加一个 180ms 的「首字节窗口」，这么久还没开始发就直接丢掉 |
| **打印机没开机时网页周期性假死** | 主循环每 10 秒用 SSL 连一次不可达的打印机，每次都卡到系统超时（好几秒甚至几十秒） | 先花最多 1 秒做 TCP 预探测，探不通就跳过这一轮（`preflight=True`） |
| **MQTT 每重连一次漏一个 socket** | `self.client = MQTTClient(...)` 直接覆盖，老对象连同它的 SSL socket 从来没被关过，跑几小时就 socket 耗尽 | 重连前先 `close_client()`，把旧连接真正断开 + 置空 |
| **点一下点动就转圈几十秒** | 手动点动直接调同步的 `bus.run()`，内部用 `time.sleep_ms` 度过整个时长，整个 uasyncio 事件循环被按住 | 改成两段式 `begin()` / `finish()`：按下瞬间吸合 + 转起来 → **立刻回包** → 后台任务 `await asyncio.sleep_ms` 计时 → 到点停电机、断开离合 |
| **点保存时网页像卡死** | `handle_mqtt_cennect` 里现场做 TLS 握手 + 订阅，打印机没开机时卡好几秒，最后还回一句「失败」 | 只落盘 + 置脏标志，由主循环后台重连；回包如实说「已保存 / 正在后台连接」 |
| **页面一慢就报「保存失败」** | 保存结果只有「成功 / 失败」两种说法，「配置其实存好了、只是还没连上」被说成失败 | 返回 `saved` / `connecting` / `connected` 三个字段，页面分别给提示 |
| **页面卡死**<br>「换料和刷新一起就卡」 | 主循环用阻塞的 `wait_msg()` 收 MQTT，把整个事件循环按住 | 改用非阻塞的 `poll_msg()`，没消息立刻返回 |
| MQTT 频繁重连 | 「每 20 轮重连一次」，而每轮都阻塞，实际几秒断一次 | 改成按时间，每 5 分钟才重建 |
| 状态灯拖慢网页 | `check_mqtt_connection()` 每秒真的发一次 `PINGREQ` | 按 5 秒节流（`MQTT_PING_INTERVAL_MS`） |
| GC 过频 | `gc.threshold(1024)`：每分配 1KB 就回收一次 | 放宽到 16KB |

> 🔴 **`FILE_CHUNK` 不要调大。** 它直接决定"服务网页时的最大单次内存分配"。
> 1KB 在任何情况下都分配得出来；一调到 40KB 就退回上面那条 OOM 故障。

这些改动都有对应的自动化测试守着（见 [本地开发与自测](#本地开发与自测)），
防止以后改回去。

---

## 硬件配置项

硬件相关的东西分两层，改完都不用动业务代码：

| 层 | 文件 | 放什么 |
| --- | --- | --- |
| **板型层** | `python_code/board_c3.py` / `board_s3.py` | 这块芯片哪些脚能用：默认接线、保留脚、strapping 脚、剩余可用 IO |
| **入口层** | `python_code/hardware_config.py` | 选板型（读 `board_select.py` → 自动识别）+ 上表这套与芯片无关的业务参数 + 上电自检 |

所以「换板子」只影响板型层，「调动作时间」只影响入口层。

| 配置项 | 默认值（C3 / S3） | 说明 |
| --- | --- | --- |
| `MOTOR_PIN_IN1` / `MOTOR_PIN_IN2` | `4` / `5`（两块板相同） | H 桥两个输入脚 |
| `MOTOR_DEAD_TIME_MS` | `30` | 换向死区时间，单位 ms |
| `CLUTCH_PINS` | C3 `(6, 7, 10, 3)` / S3 `(6, 7, 8, 9)` | 4 路电磁离合对应的 GPIO |
| `CLUTCH_ACTIVE_LEVEL` | `1` | `1` = 高电平吸合；驱动板是低电平吸合时改成 `0` |
| `CLUTCH_ENGAGE_MS` | `80` | 吸合后等待机械咬合的时间 |
| `CLUTCH_RELEASE_MS` | `60` | 断开后等待彻底脱开的时间 |
| `CLUTCH_SETTLE_MS` | `20` | 通道切换时的额外静默时间 |
| `LIMIT_SWITCH_PINS` | `(None, None, None, None)` | 到位开关，`None` = 未安装；填了 GPIO 就自动启用探测 |
| `FILAMENT_STEP_MS` | `500` | 单步推送时长 |
| `RETRACT_STEPS` / `LOAD_RETRY_TIMES` | `15` / `10` | 退料步数 / 进料重试次数（有开关时提前结束） |
| `NO_LIMIT_RETRACT_MS` | `6000` | ★ 降级模式退料时长，**需实测调整** |
| `NO_LIMIT_LOAD_MS` | `8000` | ★ 降级模式进料时长，**需实测调整** |
| `JOG_TIME_MS` | `1000` | ★ 网页手动点动的「进退响应时间」出厂默认值（毫秒）。只作用于手动点动，**不影响自动换料** |
| `JOG_MIN_MS` / `JOG_MAX_MS` | `200` / `60000` | 上面那个值的安全区间（0.2 ~ 60 秒）。网页上填超范围会被自动夹住 |
| `LED_PIN` | `2`（两块板相同） | 状态指示灯 |
| `CONFIG_FILE` | `"config.json"` | 持久化配置文件 |

只读的板型信息（自检和网页上都会用到）：

| 常量 | 说明 |
| --- | --- |
| `BOARD_ID` / `BOARD_NAME` / `BOARD_SOURCE` | 当前板型，以及「板型是怎么定下来的」 |
| `CHIP` / `GPIO_MAX` | 芯片名与 GPIO 上限（C3 是 21，S3 是 48） |
| `SAFE_OUTPUT_PINS` | 可以安全做输出的脚 |
| `SPARE_PINS` | ★ **剩余可用的干净 IO**（S3 上会列出全部 18 只） |
| `STRAPPING_SPARE_PINS` | 剩余可用的 strapping 脚（仅建议作输入） |
| `RECOMMENDED_LIMIT_SWITCH_PINS` | 这块板上到位开关的推荐脚 |

`hardware_config.validate()` 会在启动时校验引脚是否合法（重复占用、越界、
踩到 Flash/USB/UART 保留脚、strapping 误用），**按当前板型的规则**判断，
有问题直接报出来。把 `device_processing.py` 当脚本跑一次就能打印完整接线表
并逐个点动 4 个通道：

```bash
# 在设备 REPL 里（或 mpremote）执行
import device_processing

# 只想看看当前板型、用了哪些脚、还剩哪些脚
from hardware_config import describe
print(describe())
```

---

## 调试

### 上电诊断（复位原因 / 启动次数 / 引脚自检）

页面上的「上电诊断」卡片，以及串口每次上电都会打印的一段：

```
======== 上电自检 ========
复位原因 : BROWN_OUT_RESET（★ 欠压复位：供电电压掉到了阈值以下…）
启动计数 : 第 37 次（次数持续 +1 说明在反复复位）
==========================
---- 硬件配置 ----
共享电机 : IN1=GPIO4  IN2=GPIO5  换向死区=30ms
电磁离合1: GPIO6  (高电平吸合, 吸合等待80ms)
...
引脚配置自检通过：全部输出脚都在安全引脚上。
```

排查「接上负载就一直重启」的用法：网页点「重置启动计数」→ 拔电重插 →
回来看数字。**一次上电就涨了几十 = 复位循环**。

复位原因对照：

| 复位原因 | 含义 | 先查什么 |
| --- | --- | --- |
| `BROWN_OUT_RESET` | 欠压复位 | 供电功率、线径、共地、VM 滤波电容 |
| `PWRON_RESET`（反复出现） | 反复冷启动 | 同上；供电正常则查引脚是否被拉低 |
| `WDT_RESET` / `RTC_WDT_RESET` | 看门狗复位 | 有任务阻塞了事件循环 |
| `SOFT_RESET` | 软复位 | 正常（软件主动复位） |

卡片里还有一行 **空闲内存**（`/status` 的 `mem_free` 字段），低于 20KB 会标红。
配置页面有 40KB，是靠「分块发送」才发得出去的 —— 余量太小的时候，
任何一次大分配都可能失败，网页就会不稳甚至打不开。另外**任何请求出错时，
串口日志都会带上一句「空闲内存 xxx 字节」**，出问题先看这个数。

### 网页硬件面板

浏览器打开主板 IP，页面下半部分的「硬件调试」区块会显示：

- 电机当前方向（`1` 进料 / `-1` 退料 / `0` 停止）
- 4 路离合各自的吸合状态
- 累计冲突次数（**正常应始终为 0**；不为 0 说明离合驱动电路有问题）
- 每个通道的「进料 1s / 退料 1s」手动点动按钮

点动接口同样受互斥约束保护，不会出现两路同时吸合。

### 串口日志

`logout()` 会打印换料全过程，关键日志形如：

```
当前料盘:1新的料盘:3
开始退料
开始进料
换料第 1 次尝试
换料成功
```

出现 `离合体检异常` / `离合状态异常，已全部断开` 时，说明检测到了多路吸合，
请立刻断电检查离合的驱动电路是否有短路。

---

## 应用层 OTA（网页升级，不用插 USB）

### 能更新什么、不能更新什么

| 对象 | 网页 OTA | 说明 |
| --- | --- | --- |
| 全部程序逻辑（`AMS_WEB.py` / 换料逻辑 / `bambu/` …） | ✅ | 它们在文件系统里是 `.py` 源码 |
| 网页界面（`index.html`） | ✅ | 同样在文件系统里 |
| MicroPython 内核本身 | ❌ | 见下面的「为什么不做整机固件 OTA」，要动只能插 USB |

### 为什么不做「上传整机固件 BIN」

这块板子的分区表是**单个 factory 应用分区 + 2 MB littlefs**，没有 `ota_0` / `ota_1`
两个备份分区、也没有 `otadata`：

```
nvs       0x009000    24 KB
phy_init  0x00f000     4 KB
factory   0x010000  1984 KB   ← MicroPython 内核 + 本项目代码
vfs       0x200000  2048 KB   ← 文件系统
```

所以**没法**像手机那样「把新固件写进备用分区再切过去」。要那样做必须先改分区表、
用 USB 重刷一次。基于这个前提，本项目选了更实用的一条路：

> 既然「换料逻辑」和「网页界面」本来就在文件系统里（构建时直接打进 littlefs，
> 不做 `.mpy`），那就**整个替换文件系统里的文件** —— 这就是应用层 OTA。

用户如果把 `esp32c3-ams-firmware.bin` 直接拖进来，设备会**识别出来并明确提示
改用 USB 刷写**，而不是扔一句「格式错误」让人干瞪眼。

### `.ams` 更新包格式

```
偏移 0    8 字节   magic  b"AMSUPD1\n"
偏移 8    u16      文件个数 file_count
偏移 10   u16      清单字节数 manifest_bytes
偏移 12   u32      载荷总字节数 total_payload
偏移 16   manifest（每项：u8 name_len + name + u32 size + u32 crc32）
之后      各文件载荷按清单顺序首尾相接
```

`crc32` 是标准 CRC-32，**和 PC 侧 `zlib.crc32` 逐字节一致**（有测试钉住）。
生成命令：

```bash
python tools/make_update_pack.py                 # 默认输出 dist/ams-update.ams
python tools/make_update_pack.py --out dist/x.ams
```

它会把 `python_code/` 整个打进去（跳过 `__pycache__` / `.pyc`），
并且**不打包** `config.json` / `wifi.dat`（设备上这两个是用户数据）。

### 升级流程与安全设计

1. 网页上选 `.ams` 文件 → 点「上传并升级」，浏览器直接把文件的**原始字节**
   作为请求体 POST 到 `/ota_upload`（`application/octet-stream`，不用 multipart）
2. 设备**边收边写**：每收到一块就喂给 `OtaUpdate`，它负责写文件和算 CRC32。
   ★ 绝不会把几百 KB 的包先读进内存 —— ESP32-C3 的空闲堆只有几十 KB
3. 每个文件都**先写成 `名字.new` 临时文件**，写完立刻核对**长度 + CRC32**
4. **所有文件全部校验通过**之后，才把 `.new` 依次改名成正式名字
   （改名是原子操作，中途掉电最多「一部分新一部分旧」，不会出现半个文件）
5. 回包告诉浏览器「写入了几个文件、即将重启」→ 等 0.9 秒把响应发完 → 重启
6. **任何失败路径都会删掉全部 `.new` 并如实报错，绝不重启、绝不留半截文件**

另外，更新包会被当**不可信输入**处理：拒绝绝对路径、拒绝 `..`、
拒绝覆盖 `config.json` / `wifi.dat` / `boot_stat.json`（那里面是 WiFi 密码和
打印机访问码，被覆盖一次等于把设备配置清了）。

### 页面上的使用说明

「系统 → 系统升级 (OTA)」页面里能直接选包上传，并显示：

- 正在上传的文件名和大小（`… 请不要断电`）
- 成功之后：`升级完成，已写入 N 个文件，设备将在 1 秒后自动重启`
- 失败时：设备给出的中文原因（例如 `AMS_WEB.py 校验失败（CRC32 不匹配），更新包可能已损坏`）

升级过程中**不要断电**；写完之后页面会失联十几秒，重启完成后刷新即可。

> 💡 参数（单个文件上限、接收块大小、两种超时）都在 `AMS_WEB.py` 顶部：
> `OTA_MAX_BYTES` / `OTA_RECV_CHUNK` / `OTA_IDLE_TIMEOUT_MS` / `OTA_TOTAL_TIMEOUT_MS`。

---

## GitHub Actions 自动编译与发布

`.github/workflows/build.yml` 分四个环节，**每次提交都会自动跑**（push 到任意分支、
提 PR、或在网页上手动点运行）：

| Job | 做什么 |
| --- | --- |
| **语法检查与逻辑自测** | `compileall` 检查全部 Python 文件；运行 `tests/run_tests.py` 验证离合互斥、两块板引脚表等约束 |
| **交叉编译 .mpy 部署包（matrix: c3 / s3）** | 用 `mpy-cross` 把 `python_code/` 编译成 `.mpy`，**两块板各出一个包**（包内已写入对应的 `board_select.py`） |
| **构建单文件固件 BIN（matrix: c3 / s3）** | 各自的官方固件 + littlefs 文件系统镜像 → 合成可整片烧录的 BIN，并做四道校验；S3 的分区表由脚本自行解析（vfs `0x200000` 起、6MB） |
| **发布固件** | 主分支提交 → 更新滚动预发布版 `latest`；打 `v*` tag → 发正式 Release，两个板型的 bin + zip 一起上传 |

所有产物同时挂在 Actions 的 Artifacts 下（保留 30 天）和 Releases 页面：

```
esp32c3-ams-firmware.bin / .sha256      单文件固件（C3，4MB）
esp32s3-ams-firmware.bin / .sha256      单文件固件（S3 42 针，8MB）
esp32c3-ams-mpy.zip                     .mpy 部署包（C3，含 BOARD = "c3"）
esp32s3-ams-mpy.zip                     .mpy 部署包（S3，含 BOARD = "s3"）
```

**发布规则**

| 触发方式 | 结果 |
| --- | --- |
| push 到 `main` | 自动覆盖 Releases 里的 `latest`（预发布），下载地址固定不变 |
| push tag `v1.0.0` | 创建正式 Release `v1.0.0` |
| Pull Request | 只编译校验，不发布 |

```bash
git tag v1.0.0
git push origin v1.0.0
```

**单文件固件是怎么做出来的**

`tools/make_firmware_bin.py` 负责整个流程，核心是「文件系统必须与设备端同源」：

1. 从官方固件里**解析分区表**（不写死偏移），找到 `vfs` 分区（本板 `0x200000` 起，2MB）；
2. 用 `tools/lfs_mkfs.c` 生成 littlefs 镜像 —— 它链接的是**上游 littlefs 2.8**，
   与 MicroPython v1.23 内置的 `lib/littlefs` 完全一致，参数也照抄设备端
   `VfsLfs2.mkfs`（`block_size=4096`、`block_cycles=100`、`name_max=255` …）；
3. 与官方固件拼成从 `0x0` 覆盖整片 Flash 的 BIN；
4. 四道校验：用同一份 littlefs 代码回读并逐字节比对 → 产物重新解析镜像头与分区表 →
   校验块 0/1 偏移 8 处的 `littlefs` 魔数 → 再用另一套独立实现（littlefs-python）
   把 BIN 里的文件系统读一遍。

> ⚠️ 这些校验不是摆设。ESP32 端 `_boot.py` 挂载失败会走
> `inisetup.check_bootsec()`，只要首扇区不是 `0xFF` 就判定「文件系统损坏」并进入
> **死循环**，所以必须一次做对。脚本还会联网核对 littlefs 版本号，不一致直接报错停止。

**升级 MicroPython 版本**：改 `.github/workflows/build.yml` 顶部那几个变量，
以及 `firmware` job 的 matrix 里两块板各自的固件链接与 SHA256，文件里对每一项都有说明。
其中 `MICROPYTHON_VERSION` 与 `LITTLEFS_VERSION` 的配套关系由脚本自动检查。

**本地等价操作**：

```bash
python tests/run_tests.py                 # 自测
python tools/build_mpy.py                 # 交叉编译，默认 C3 + S3 各一个包
python tools/build_mpy.py --board s3      # 只编 S3

# 单文件固件（需要先编译那个小工具，CI 里是自动完成的）
gcc -O2 -o tools/build/lfs_mkfs tools/lfs_mkfs.c \
    <littlefs源码>/lfs.c <littlefs源码>/lfs_util.c -I<littlefs源码>

# C3
python tools/make_firmware_bin.py --board c3 \
  --firmware-url "https://micropython.org/resources/firmware/ESP32_GENERIC_C3-20240602-v1.23.0.bin" \
  --firmware-sha256 "8058b7d6eb55f8124fbdcc797e2e8b39ae947a18df635567e02c8786874c04fd" \
  --out dist/esp32c3-ams-firmware.bin

# S3（42 针）
python tools/make_firmware_bin.py --board s3 \
  --firmware-url "https://micropython.org/resources/firmware/ESP32_GENERIC_S3-20240602-v1.23.0.bin" \
  --firmware-sha256 "b91080af2e9b78bad4308f98bb6187567cae24ed77cd7f48ef99b47af3ef0555" \
  --out dist/esp32s3-ams-firmware.bin
```

> 不写 `--out` 时按板型自动命名成 `dist/<芯片>-ams-firmware.bin`。

> 本地生成固件需要 gcc；不想装就直接用 CI 产物（每次提交都会自动构建）。

---

## 本地开发与自测

核心的硬件安全逻辑可以在 PC 上直接验证，**不需要板子**。`tests/mpy_stubs/`
提供了一套 MicroPython 模块桩（`machine`、`network`、`ujson`、`uasyncio`、
`umqtt`），它会记录所有 GPIO 的写入，从而断言硬件约束。

```bash
python tests/run_tests.py
```

共 116 项测试，分六块。

**① 电磁离合安全约束**（核心，改动硬件层时必看）

| 测试 | 验证内容 |
| --- | --- |
| `test_only_one_clutch_engaged_at_a_time` | ★ 依次吸合 4 路离合，任何时刻吸合数都**不能超过 1** |
| `test_switch_channel_always_passes_through_all_off` | 切换通道时必须先经过「全部断开」，不允许出现两路咬合的瞬间 |
| `test_assert_single_detects_external_fault` | 模拟驱动电路故障导致两路吸合，体检必须发现并立即全部断开 |
| `test_hold_releases_on_exception` | 动作中途抛异常，也必须释放离合、停电机 |
| `test_motor_direction_and_dead_time` | 换向必须经过「两脚都拉低」的死区，H 桥不允许上下管同时导通 |
| `test_hardware_config_valid` | 引脚配置必须避开**当前板型**的 Flash / USB / UART 保留脚（C3 与 S3 规则不同） |

**② 联网与配网**

| 测试 | 验证内容 |
| --- | --- |
| `test_network_boot_connect_does_not_scan` | ★ 上电自动联网必须直连已保存的 WiFi，`scan()` 调用次数必须是 0 |
| `test_network_falls_back_to_ap_after_three_attempts` | 连不上时恰好尝试 3 次，然后返回 `None` 触发开热点 |
| `test_network_requires_real_ip_not_just_association` | 只关联上 AP、没拿到 IP 不算连接成功 |
| `test_network_scan_is_cached_and_sorted` | 扫描结果按信号排序去重，缓存有效期内不重复扫描 |
| `test_network_missing_wifi_dat_is_safe` | 全新板子没有 `wifi.dat` 时必须安全降级，不能抛异常 |

**③ 网页不会变慢 / 不会打不开的回归保护**

| 测试 | 验证内容 |
| --- | --- |
| `test_web_root_is_streamed_not_read_into_ram` | ★ 页面必须分块流式发送：不能有整份 `f.read()`、不能整份内存缓存、单块 ≤ 2KB |
| `test_web_streams_real_index_html_byte_for_byte` | ★ 拿真机上那份 40KB 页面实跑：逐字节一致，且**单次发送不超过 1KB** |
| `test_web_memory_error_sends_tiny_page_not_blank` | 内存不足时回一个极小的 503 提示页（且只在「一个字都没发出去」时才补） |
| `test_web_send_file_reports_missing_file` | 页面文件缺失要回 500，不能把异常抛给请求循环 |
| `test_web_header_read_is_not_blocking` | 读请求头必须非阻塞 + `await` 让步，且有总等待上限 |
| `test_ams_loop_does_not_block_on_wait_msg` | ★ 主循环里不能再出现阻塞收包，必须用 `poll_msg()` |
| `test_ams_loop_waits_for_wifi_before_mqtt` | WiFi 没连上时不要空转重连 MQTT（AP 模式下日志会被刷爆） |
| `test_ams_reconnect_is_time_based` | 定期重连要按时间节流（≥1 分钟），不能几秒断一次 |
| `test_mqtt_ping_throttling_behaviour` | 连续探测时，节流窗口内只应真的 `ping` 一次 |
| `test_web_status_aggregates_everything` | `/status` 必须把页面需要的字段一次给全（含 `mem_free`） |
| `test_request_reader_waits_for_post_body` | ★ 必须按 `Content-Length` 把 POST 请求体读完（否则保存提示 404） |
| `test_read_request_collects_body_arriving_in_a_later_segment` | ★ 假 socket 把请求头和请求体**分成两段**喂进去，必须读全并解析出 JSON |
| `test_send_response_handles_non_ascii_content_length` | ★ 中文响应的 `Content-Length` 必须是 UTF-8 字节数，单块发送要足够小 |
| `test_content_length_parsing_is_robust` | 大小写、缺字段、非数字的 `Content-Length` 都要能安全处理 |
| `test_write_routes_never_answer_404_for_empty_body` | ★ 写接口收到空请求体要回 **400 并说明原因**，不能回 404 误导 |
| `test_status_is_small_enough_for_the_board` | ★ `/status` 的 JSON 必须 < 2.4KB，SSID 限量 12 个 |
| `test_status_survives_broken_fields` | ★ 单个字段取值失败时 `/status` 仍要整体可用（不能整页空白） |
| `test_log_endpoint_returns_recent_lines` | `/log` 要从环形缓冲取值且限量 |
| `test_log_ring_buffer_is_bounded` | ★ 日志缓冲限量 24 行 × 100 字符，`recent()` 必须返回副本 |
| `test_mqtt_config_is_saved_before_connecting` | ★ MQTT 配置必须「先落盘，再连接」，并返回 `saved` / `connected` |
| `test_mqtt_defaults_fill_blank_fields` | 用户名 / 客户端名 / 端口留空时用默认值补齐 |
| `test_wifi_connect_closes_ap_after_success` | ★ 配网成功后要关热点，且必须先回包再关 |
| `test_ap_can_be_toggled_from_web` | ★ 网页必须能把配置热点再打开（否则换 WiFi 只能重刷固件） |

**④ 复位诊断与引脚安全**（「接上负载就一直重启」的回归保护）

| 测试 | 验证内容 |
| --- | --- |
| `test_strapping_pins_include_gpio3` | ★ `GPIO3` 必须被列为 strapping 脚（早期版本漏了它） |
| `test_motor_on_strapping_pin_is_hard_error` | ★ 电机接到 `GPIO2` / `GPIO3` 必须直接判错，`validate()` 不通过 |
| `test_default_motor_pins_are_safe` | 默认电机引脚必须在安全输出集合里 |
| `test_clutch_on_strapping_pin_is_only_warning` | 离合挂 `GPIO3`（ULN2803 输入高阻）只警告，不能让板子起不来 |
| `test_make_safe_powers_everything_down` | ★ 上电第一件事必须把电机 / 离合 / LED 置到不上电电平 |
| `test_make_safe_survives_bad_pin` | 单个脚初始化失败也不能抛异常挡住启动 |
| `test_boot_py_safe_before_anything_else` | `boot.py` 必须是 `make_safe → capture → record_boot` 的顺序 |
| `test_reset_cause_is_captured_and_reported` | 复位原因必须能识别，且能序列化给网页 |
| `test_boot_count_increments_and_clears` | 启动计数能累加、能清零（数字疯涨 = 复位循环） |
| `test_status_exposes_reset_diagnostics` | ★ `/status` 必须带 `reset` 和 `boot_safety` 字段（但不带 `report`，那会把接口撑爆） |
| `test_led_can_be_disabled` | `LED_PIN = None` 时必须优雅跳过，不能 `AttributeError` |

**⑤ 网页界面行为**（这些是「用户能直接看见」的约定，最容易被改回去）

| 测试 | 验证内容 |
| --- | --- |
| `test_page_renders_four_channels_without_waiting` | ★ 默认就要画出 4 个通道和 4 路点动按钮，**不能等接口** |
| `test_page_wifi_card_only_in_ap_mode` | ★ WiFi 配置只在配置热点开启时出现，热点一关就消失并跳回运行状态（靠 `.item.hide` 这条 CSS 规则） |
| `test_page_menu_starts_folded` | ★ 每个目录默认折叠，展开状态存 localStorage |
| `test_page_directories_stay_folded_on_boot` | ★ 开机 / 刷新时**一个目录都不许自动展开**：`showPage` 的自动展开只在用户点菜单时发生 |
| `test_page_has_left_menu_and_log_panel` | 左侧菜单 + 右侧内容 + 右下角常驻日志，且新日志会自动滚到底 |
| `test_page_reports_mqtt_save_result_precisely` | 「已保存但连不上」和「彻底失败」要给不同提示 |
| `test_page_never_builds_request_body_outside_json` | 写操作必须带 JSON 请求体和 `Content-Type` |
| `test_page_has_ota_menu_and_upload` | ★ 系统菜单里要有「系统升级 (OTA)」，且真的把文件 POST 到 `/ota_upload` |
| `test_page_ota_hints_usb_for_firmware_bin` | 页面要写明整机固件 BIN 不能走这里、要点名那个文件名 |
| `test_page_hardware_has_jog_time_setting` | ★ 硬件调试页要有「进退响应时间」输入框，并写明「不影响自动换料」 |
| `test_page_jog_buttons_follow_the_device_setting` | ★ 点动按钮上的秒数跟着设备设置走，且正在输入时不被 2 秒轮询覆盖 |
| `test_page_mqtt_status_distinguishes_configured_but_retrying` | 页面要区分「还没配」和「配好了、后台正在重试」 |

**⑥ 这一版新增：卡顿 / 转圈 / 刷新不出页面的回归保护**

| 测试 | 验证内容 |
| --- | --- |
| `test_status_never_touches_network` | ★ `/status` 里不能再出现 `check_mqtt_connection`（真实网络 I/O）；把所有网络入口换成「一碰就炸」，接口仍必须可用 |
| `test_mqtt_alive_cached_does_no_io` | ★ `mqtt_alive_cached()` 一次网络 I/O 都不做（网页每 2 秒读它一次） |
| `test_mqtt_ping_has_hard_timeout` | ★ `ping` 有 0.8 秒硬超时，且 ping 完把 socket 超时还原成不限制 |
| `test_mqtt_preflight_skips_unreachable_printer` | ★ 打印机连不上时跳过这一轮，**绝不**去构造 SSL 连接 |
| `test_web_uses_worker_pool_and_big_backlog` | ★ 多 worker 并发 + `listen(8)`；`run_web_loop` 本身不能再直接处理请求（否则退回串行） |
| `test_web_first_byte_window_is_short` | ★ 浏览器的「预连接」套接字要在 180ms 内被丢掉 |
| `test_web_routing_works_on_raw_bytes_headers` | ★ 路由正则必须能解析 socket 读来的 **bytes** 请求行（str 模式匹配 bytes 会每请求都 500） |
| `test_bus_two_phase_api_is_non_blocking` | ★ `begin()` 立刻返回并让电机转起来；`finish()` 用 `finally` 兜底断开；忙时拒绝切换通道；`stop` 抛异常也不卡在忙态 |
| `test_jog_does_not_block_event_loop` | ★ 点动不能再调同步的 `bus.run()`；计时必须用 `await asyncio.sleep_ms` |
| `test_hardware_test_replies_before_the_action_finishes` | ★ 回包那一刻电机已经在转、后台任务还没跑完；跑完后电机停、离合断开、总线空闲 |
| `test_jog_rejects_when_bus_is_busy` | ★ 忙时立刻拒绝并说明，**不排队** |
| `test_hardware_test_validates_input` | 非法通道 / 方向回 400 并说人话，拒绝后电机停、离合断开 |
| `test_jog_time_clamped_to_safe_range` | ★ 进退响应时间夹在 0.2~60 秒，非数字退回默认 |
| `test_jog_time_is_uniform_for_four_channels` | ★ 一个值管 4 个通道，并写进 `config.json` |
| `test_jog_time_survives_restart` | ★ 重启后从配置恢复；坏值 / 超范围值都要安全处理 |
| `test_jog_set_endpoint_clamps_and_reports` | ★ `/jog_set` 如实报告「实际生效」的秒数，被夹过要说明 |
| `test_jog_time_only_affects_manual_jog` | ★ 自动换料流程与驱动层都不许读 `jog_ms` |
| `test_status_exposes_jog_ms_and_mqtt_configured` | `/status` 要带 `jog_ms` 和 `mqtt_configured` |
| `test_hardware_status_reports_busy` | 硬件状态要带 `busy`，页面才能显示「正在动作」 |
| `test_mqtt_config_is_saved_before_connecting` | ★ MQTT 配置「先落盘，再交给后台连接」，请求里**不做** TLS 握手 |
| `test_mqtt_save_reports_honest_status` | ★ 保存要如实回 `saved` / `connecting` / `connected`，并置脏标志 |
| `test_mqtt_save_rejects_blank_required_fields` | 必填项留空回 400 并点名中文字段，且**绝不写盘** |
| `test_ams_loop_reconnects_when_mqtt_config_is_dirty` | ★ 主循环看到脏标志要 `close_client()` 后用新参数重连 |
| `test_close_client_releases_old_socket` | ★ 重连前必须真正断开旧连接（否则每重连一次漏一个 socket） |
| `test_ota_crc32_matches_zlib` | ★ 纯 Python CRC32 与 `zlib.crc32` 逐字节一致，且支持分块增量 |
| `test_ota_pack_roundtrips_byte_for_byte` | ★ 更新包按不规则分块喂入后逐字节还原，子目录自动创建，不留 `.new` |
| `test_ota_pack_rejects_corrupt_payload` | ★ 改动一个字节 → CRC 发现并中止，绝不写出正式文件 |
| `test_ota_pack_rejects_truncated_upload` | ★ 只收了一半 → `finish()` 拒绝，不留半截文件 |
| `test_ota_rejects_firmware_bin_with_helpful_message` | ★ 整机固件 BIN 被识别并明确提示「改走 USB」 |
| `test_ota_rejects_unsafe_names` | ★ 拒绝绝对路径 / `..` / 覆盖 `config.json`、`wifi.dat`、`boot_stat.json` |
| `test_ota_route_is_streamed` | ★ `ota_upload` 走流式路径，且在「读请求体」之前分流 |
| `test_ota_upload_endpoint_writes_files_then_asks_for_reboot` | ★ 端到端：`POST /ota_upload` 把文件写进文件系统并回 `reboot:true` |
| `test_ota_upload_endpoint_rejects_bad_pack` | ★ 坏包回 400，一个文件都不写；`Content-Length` 为 0 也挡住 |
| `test_reboot_is_skipped_in_selftest_mode` | `allow_reboot=False` 时不真重启（桌面自测用） |

**⑦ 两块开发板（ESP32-C3 / ESP32-S3）的引脚表**

两块板共用一套业务代码，差异全在 `board_c3.py` / `board_s3.py`。
这一组测试把**两份表都**拉出来校验，避免「只测了 C3、S3 那份写错了没人发现」。

| 测试 | 验证内容 |
| --- | --- |
| `test_board_c3_pin_table_is_valid` | ★ C3 那份表：引脚不越界、不碰保留脚、电机在安全输出脚上、剩余 IO 不漏报 |
| `test_board_s3_pin_table_is_valid` | ★ S3（42 针）那份表：同样的全套约束，`GPIO_MAX` 是 48 |
| `test_s3_clutches_all_land_on_clean_pins` | ★ S3 的 4 路离合全在干净脚（`6/7/8/9`）上，一个都没落在 strapping 脚 |
| `test_s3_lists_every_spare_io_pin` | ★ S3 剩余 IO = 25 只安全输出脚 − 已占 7 只 = **18 只**，且必须全部列出；保留脚一个都不许混进来 |
| `test_board_files_agree_on_the_shared_contract` | 两份表必须提供同一套常量名（`hardware_config` 才能无差别加载）；识别关键字不能互相包含 |
| `test_built_board_select_wins_over_chip_detection` | ★ 编译期写入的 `board_select.py` 优先级最高 —— 这就是「编译时自动套用对应配置」 |
| `test_board_falls_back_to_chip_name_detection` | 没有 `board_select.py` 时按 `os.uname().machine` 识别；认不出来按 C3 处理并提示 |
| `test_current_board_config_matches_the_selected_board_file` | `hardware_config` 导出的必须就是所选板型文件里的那一套；接线表要打出板型与剩余 IO |

改动相应模块后请先跑一遍再上传。

### 页面的本地预览

`index.html` 依赖 `/status` 等接口拿数据，直接用浏览器打开文件的话页面会一直
显示「加载中」，看不出真实效果。用这个小服务可以在电脑上完整跑起来：

```bash
python tools/preview_server.py        # 默认 http://127.0.0.1:8099
python tools/preview_server.py 9000   # 换端口
python tools/preview_server.py 9000 ap   # ★ 以「配置热点」模式启动
```

`ap` 那个参数会假装设备处于配网模式（热点开着、没联网），用来检查
左侧菜单里「WiFi 配置」有没有正确出现。不带参数就是普通的「已联网」状态。

它只读 `python_code/index.html`，用假数据补齐接口，不写任何文件、不参与固件构建。
改页面时建议边改边看，尤其是颜色对话框、左侧菜单和手机端的排版。

**OTA 上传在预览里是"只演练、不落盘"的**：把 `.ams` 拖进去会真的走一遍
分包接收 + CRC32 校验，然后告诉你"通过 N 个文件"，但文件写在一个临时目录里，
校验完就删掉 —— 不会覆盖你的 `python_code/`。想试"整机 BIN 会被拒绝"的效果，
直接把 `dist/esp32c3-ams-firmware.bin` 传上去即可，应当看到提示改走 USB。

> 预览服务是多线程的。因为它要一边收几百 KB 的更新包，一边响应页面每 2 秒
> 的 `/status` 和 `/log` 轮询；单线程的话轮询会被上传挡住，浏览器等不到响应
> 就会把上传连接一起掐掉，看起来像"升级失败"。

---

## 常见问题

<details>
<summary><b>★ WiFi 能连上、能 ping 通，但配置网页打不开 / 一直转圈（ESP32-C3 特有）</b></summary>

**根因是内存，不是网络。** 这是本项目在 C3 上最典型、也最容易被误判成「网络问题」
的故障。实测数据：

| 状态 | 空闲堆 | 传 40KB+ 的 `index.html` |
| --- | --- | --- |
| 不加载应用 | ~149KB | 5.7 秒发完，链路正常 |
| 加载应用后 | ~60KB | 第一个 TCP 分段就 `OSError(113)`，重传 9.4 秒后放弃，射频卡死，只能复位 |

原因是 **ESP32 的 WiFi 驱动收发数据时要动态申请「连续」内存做收发缓冲**，
而 MicroPython 的 GC 不做压缩 —— 应用 import 完之后空闲堆虽然还有 60KB，
但最大连续块可能只有几 KB，于是驱动申请不到缓冲，链路就断了。
表现就是 ping 得通、TCP 连接超时、串口里刷 `ECONNABORTED` / `WiFi 已断开`。

> 加 OTA 功能之后应用体积变大，这个问题会从「偶发」变成「必然」——
> 这也是「没加 OTA 之前只是慢，加了之后网页完全打不开」的原因。

**怎么处理（按推荐顺序）：**

1. **改用 ESP32-S3（42 针）** —— 这是根治办法。512KB SRAM，
   同一个应用跑起来余量充足，并且不必再用 `.mpy` 省内存。见
   [ESP32-S3（42 针）可用 IO](#esp32-s342-针可用-io)。
2. **在 C3 上尽量省内存**：
   - 用 `.mpy` 部署包而不是 `.py` 源码（`python tools/build_mpy.py --board c3`），
     字节码导入时不需要在设备端重新编译，省下可观内存；
   - 别在设备上跑 `board_override.py` 之类额外脚本；
   - 确认没有别的东西在占内存（例如关掉不用的状态灯不会省多少，但能省一点）。
3. **确认 WiFi 省电模式已关**：`main.py` 启动时会把 AP/STA 的
   `pm` 都设成 `0`（`WIFI_PS_NONE`）。ESP32 默认是 `pm=1`（modem sleep），
   大流量传输时会周期性休眠，加剧断链。

```python
# 在设备 REPL 里看空闲堆和各区域的「最大连续块」—— 关键指标是这个，不是总空闲量
import gc, esp32
gc.collect()
print("空闲堆 =", gc.mem_free())
for total, free, largest, minimum in esp32.idf_heap_info(esp32.HEAP_DATA):
    print("  区域: 总 %d / 空闲 %d / 最大连续 %d" % (total, free, largest))
```

</details>

<details>
<summary><b>★ 接上负载后一直重启、电机一直有电流声、网页打不开</b></summary>

**先对号入座，再动手改线：**

| 现象 | 八成是 | 怎么处理 |
| --- | --- | --- |
| 电机「一会长鸣、一会间隔响」 | IN1/IN2 接到了 `GPIO2`，而 `GPIO2` 上还挂着 1kHz 的状态灯 PWM | 把电机改回 `GPIO4` / `GPIO5` |
| 反复重启、网页永远打不开 | 电机接到了 `GPIO2` / `GPIO3`（strapping 脚），AT8236 输入的内置下拉把它拉低 | 把电机改回 `GPIO4` / `GPIO5` |
| 空载正常、一挂负载就重启 | 电源带不动（欠压复位） | 给 AT8236 的 VM 单独供电、加粗线径、共地 |
| 电机有电流声但转不起来 | AT8236 限流设得太小（VREF / ISEN） | 放宽限流，或把 ISEN 直接接地 |

**第一步：确认引脚没接错。**

电机 `IN1` / `IN2` 只能是**当前板型安全输出脚**里的引脚：

- **ESP32-S3**：`GPIO1 / GPIO2 / GPIO4~GPIO18 / GPIO21 / GPIO38~GPIO42 / GPIO47 / GPIO48`
  （避开 `GPIO0 / GPIO3 / GPIO45 / GPIO46` 这四个 strapping 脚）
- **ESP32-C3**：`GPIO0 / GPIO1 / GPIO4 / GPIO5 / GPIO6 / GPIO7 / GPIO10`
  （避开 `GPIO2` 和 `GPIO3` —— 它们是 strapping 启动模式脚，
  AT8236 的输入内置下拉会把它们在上电瞬间拉低，一接上就起不来）

拿不准就上电看日志里的「硬件配置」那段，它会直接告诉你当前板型、用了哪些脚、
以及哪些脚还剩着（`hardware_config.describe()`）。

**第二步：看「上电诊断」卡片 / 串口日志。**

```
======== 上电自检 ========
复位原因 : BROWN_OUT_RESET（★ 欠压复位：供电电压掉到了阈值以下…）
启动计数 : 第 37 次（次数持续 +1 说明在反复复位）
==========================
```

- `BROWN_OUT_RESET` → 供电问题。给 VM 单独供电、加粗线、共地到同一点。
- `PWRON_RESET` 且启动次数疯涨 → 芯片在反复掉电，同样先查供电；
  供电没问题就是引脚被拉低导致进不了启动模式。
- `WDT_RESET` → 有任务卡住了事件循环（老代码里的 `wait_msg()` 就是这个毛病，
  现已改成非阻塞轮询）。
- 「引脚自检」显示未通过 → 照着红字提示把线改到安全引脚上。

启动计数可以在网页上点「重置启动计数」清零：**清零 → 拔电重插 → 再看数字**，
一次上电就涨了几十，就确定是复位循环。

**第三步：把负载摘掉验证。**

断开电机和离合，只留 ESP32 供电。如果这样能正常启动、网页能开，
就说明是「负载把电源拉塌」而不是固件问题。再逐个接上电机 / 离合，
接哪一个出问题就查哪一路。

**为什么 GPIO2 上会有 1kHz 的 PWM？** 状态灯就是 1kHz
（`AMS_WEB.py` 里 `PWM(Pin(LED_PIN))`）：MQTT 连上时 `duty(1000)` 常亮，
只连上 WiFi 时 0.5 秒亮 / 0.5 秒灭。所以电机跟着它叫的规律正好是
「长鸣 ↔ 间隔响」，一看就能对上。
</details>

<details>
<summary><b>板子上电后没有反应 / 找不到 AMS_WIFI 热点</b></summary>

1. 确认 `main.py` 已经上传到设备**根目录**（不是子目录）。
   （用单文件固件整片烧录时，文件已经在文件系统里，这条基本不会踩到。）
2. 用串口工具（Thonny / `mpremote`）连上后看有没有报错，特别是
   `.mpy` 版本不匹配的 `ValueError: incompatible .mpy file`。
3. 确认 `boot.py` 和 `main.py` 是 `.py` 而不是 `.mpy` —— 这两个文件
   MicroPython 是直接 `exec` 文件内容的，不能编译成字节码。
</details>

<details>
<summary><b>串口反复打印 The filesystem appears to be corrupted / 一直重启</b></summary>

这是 MicroPython 挂载文件系统失败后的保护逻辑（`inisetup.check_bootsec()`）：
只要分区首扇区不是 `0xFF`，它就认定文件系统损坏，并进入死循环，不执行任何用户代码。

**正常烧录本仓库的单文件固件不会出现这个问题** —— 构建流程里有四道校验专门防它
（见 [GitHub Actions 自动编译与发布](#github-actions-自动编译与发布)）。一旦遇到，这样救回来：

```bash
# 1) 彻底擦除整片 Flash（关键，必须做）
esptool.py --chip esp32c3 --port COM5 erase_flash
# 2) 重新烧录
esptool.py --chip esp32c3 --port COM5 write_flash -z 0x0 esp32c3-ams-firmware.bin
```

反复出现的话，通常是固件版本与文件系统格式不配套（例如固件换了版本、但文件系统镜像
还是按旧版 littlefs 生成的），或者自己改过分区表。用本仓库 CI 产出的固件可避免。
</details>

<details>
<summary><b>LED 闪烁但不常亮，换料不动作</b></summary>

闪烁表示只连上了 WiFi，MQTT 没连上。检查：
- 打印机 IP / 序列号 / 访问码是否填对（访问码是 8 位，不是局域网密码）
- 主板和打印机是否在同一个网段
- 打印机固件版本是否低于 `01.03.01.00`
</details>

<details>
<summary><b>打印机报「耗材缺失」或料没送到位</b></summary>

当前没有到位开关，送料靠时间控制。把 `hardware_config.py` 里的
`NO_LIMIT_LOAD_MS` 调大一些（比如从 8000 调到 10000），逐步试到刚好够。
反过来，如果发现料被顶弯或在缓冲区堆积，就调小。
</details>

<details>
<summary><b>换料时出现断料 / 打印机报 AMS 异常</b></summary>

1. **首先检查是不是两路离合同时吸合了**。打开网页硬件面板看「冲突次数」，
   不为 0 就说明检测到过违规状态，通常是离合驱动电路短路或续流二极管没接。
2. 确认续流二极管已经反并联在每一路线圈两端。
3. 确认 4 路离合不是共用一根细电源线 —— 浪涌电流会拉塌电压。
</details>

<details>
<summary><b>网页打不开 / 找不到主板 IP</b></summary>

1. 首次使用：连热点 `AMS_WIFI`（密码 `A12345678`），访问 `192.168.4.1`。
2. 已配好的：在路由器后台找设备 IP，或看串口日志里打印的地址。
3. 换过 WiFi 或改了密码：板子直连失败 3 次后会自动重新开热点，连上去重新配。
4. 如果只连得上 WiFi 却拿不到 IP（路由器没开 DHCP、或连的是 5G 频段），
   串口会打印 `WiFi 连接失败: xxx（找不到该 WiFi）` 之类的状态，据此排查。
   **ESP32-C3 只支持 2.4G 频段**，5G SSID 是连不上的。
</details>

<details>
<summary><b>网页打开很慢 / 偶尔刷新不出来 / 一卡几十秒像崩溃了一样</b></summary>

这几个问题在本版本已经修掉了，对应原因分别是：

- **慢** —— `index.html` 以前是逐行发送、每行还 `await sleep(10ms)`，400 多行的
  页面光发 HTML 就要 4 秒以上；再加上 accept 循环里 `await sleep(500ms)`，
  每个请求都要多等几百毫秒。现在用 `os.stat` 取长度、分块流式发送，
  轮询间隔 20ms。
- **偶尔打不开** —— 读请求头原来是阻塞 `recv` + 3 秒超时。浏览器会开「预连接」
  套接字却什么都不发，服务端就在那里卡满 3 秒，期间所有任务停摆。现在是非阻塞
  读 + `await` 让步，总等待上限 0.6 秒。
- 还有一个隐藏元凶：主循环用阻塞的 `wait_msg()` 收 MQTT，没有消息时会把整个
  uasyncio 事件循环按住，Web 和状态灯任务全被饿死。现在改用非阻塞 `poll_msg()`。
- **一卡几十秒** —— `/status` 里原来调 `check_mqtt_connection()`，它会**真的在
  SSL 上发一次 PINGREQ**。打印机连接一旦半死（拔电、换网、休眠），这个阻塞写
  会一直卡到 TCP 自己超时 —— 几十秒；而 `/status` 是每 2 秒被轮询一次的，
  于是网页周期性假死、看起来「像崩溃了」。现在 `/status` **只读主循环留下的
  缓存标志**，一次网络 I/O 都不做；真实探测仍由主循环做，但带 0.8 秒硬超时。
  同理，主循环连打印机之前会先花最多 1 秒做 TCP 预探测，打印机没开机时
  直接跳过这一轮，不再「每 10 秒冻一次、每次好几秒」。
- **要刷好几次才出来** —— 三件事凑在一起：① 服务端是
  `accept → 处理 → accept` 的**串行**循环，一个慢连接就把后面所有请求全堵住；
  ② `listen(2)` 太小，浏览器一次页面加载开 6 个连接，多出来的 SYN 被内核直接
  丢掉，由浏览器按 TCP 退避（1s→2s→4s…）重试；③ 浏览器的「预连接」套接字
  什么都不发，服务端却给每个白等 600ms，6 个连接就是 3.6 秒。
  现在：**3 个 worker 轮流 accept**（读请求头那段是 `await` 让步的，并发是真的）、
  `listen(8)`、再加一个 **180ms 的「首字节窗口」**——这么久还没开始发就直接丢掉。

如果你刷了旧固件还有这个问题，重新下载 Releases 里最新的
`esp32c3-ams-firmware.bin` 整片烧一次即可，或者用网页上的
[系统升级 (OTA)](#应用层-ota网页升级不用插-usb) 上传 `.ams` 包。

> 例外：**正在换料的那十几秒页面会卡一下**，这是有意为之。换料要精确控制电机
> 时序，不能被协程调度打断。换料结束后页面会自己恢复。
>
> 另一个例外：**升级（OTA）写文件那段时间**页面也会卡，因为写入是同步的。
> 属正常现象，几秒到十几秒。
</details>

<details>
<summary><b>网页上点一下点动，一直在转圈，几十秒后才有动作</b></summary>

这是**手动点动原来是同步阻塞**导致的（已修）。

旧实现按一下按钮就直接调 `bus.run()`，而 `run()` 内部用 `time.sleep_ms`
度过整个 `times_ms`。也就是说，**整个 uasyncio 事件循环被按住好几秒**：
网页转圈、其它请求全排队、状态灯也停摆。感受上就是「按一下等半天」。

现在改成**两段式**：

```
上半场（立刻做）：吸合离合 → 让电机转起来 → 立刻回包（几十毫秒）
下半场（后台做）：await asyncio.sleep_ms(时长) → 停电机 → 断开全部离合
```

- 按下按钮**立刻**就开始动作并回响应，网页不转圈
- 动作期间再按别的通道，会被**明确拒绝**并提示「通道X 正在动作中，等它停下来再按」，
  **不会排队**（排队正是「等几十秒」的观感来源）
- 点动期间网页依然流畅，因为计时用的是 `await asyncio.sleep_ms`（会让出 CPU）

如果你刷的还是旧固件，升到最新版本即可。
</details>

<details>
<summary><b>想改手动点动的转动时长 / 改了会不会影响自动换料</b></summary>

到「打印 → 硬件调试」页面，最上面有一个 **「进退响应时间（4 个通道统一用这一个值）」**
区块：

- 填 **0.2 ~ 60 秒**，点「保存响应时间」
- 这个值**存在设备里**（`config.json` 的 `jog_ms`），重启也记得
- 4 个通道**统一用这一个值**，不用一个一个设
- 填超范围会被自动夹到安全区间，页面提示里会写明「已按安全范围调整」

> ⚠️ **它只影响下面那些手动点动按钮，不会改变自动换料时的转动时长。**
> 自动换料走的是 `NO_LIMIT_LOAD_MS` / `NO_LIMIT_RETRACT_MS` / `FILAMENT_STEP_MS`
> 那一套（在 `hardware_config.py` 里），跟这个值完全无关。

改完之后，点动按钮上的文案（「进料 1 秒」）会跟着变成新的秒数。
</details>

<details>
<summary><b>点「保存并连接」提示失败，可是重启几次它自己又连上了</b></summary>

这是**旧版本「先把结果说死」的毛病**（已修）。

旧逻辑在保存请求里**现场做 TLS 握手 + 订阅**，然后按结果回一句「成功」或「失败」。
可是：

1. TLS 握手是阻塞的，打印机没开机 / 不在同一网段时会卡好几秒，网页看着像卡死；
2. 更要命的是，**配置其实已经写进 `config.json` 了**，只是「当场没连上」——
   而重启之后主循环拿新配置一连就成功。用户看到的自然就是
   「提示失败，但重启几次它自己又连上了」这种自相矛盾的现象。

现在改成 **先落盘，再交给后台连接**：

| 返回字段 | 含义 |
| --- | --- |
| `saved` | 配置已经写进设备（**一定**为真，除非校验没过） |
| `connecting` | 已通知主循环，正在后台重连 |
| `connected` | 当前这一刻 MQTT 是否已经连上（纯读缓存，不做探测） |

页面上会分别给出提示：

- 「配置已保存，正在后台连接打印机…连上后『运行状态』里的 MQTT 会变绿」
- 设备当前没联网时：「配置已保存。设备当前没联网，联网后会自动连接打印机，不用再改设置」

另外，只有 **打印机 IP / 序列号 / 访问码** 是必填，用户名、客户端名、端口留空会
自动填 `bblp` / `mqttx_3c73cd31` / `8883`。
</details>

<details>
<summary><b>怎么在线升级（OTA）？能不能直接上传那个固件 BIN？</b></summary>

到「系统 → 系统升级 (OTA)」页面，选 `.ams` 更新包上传即可，
设备会自动写文件并重启，**不用插 USB、不用重新配网**。详见
[应用层 OTA](#应用层-ota网页升级不用插-usb)。

**但整机固件 BIN（`esp32c3-ams-firmware.bin` / `esp32s3-ams-firmware.bin`）
不能走这里。** 那块 BIN 是**整机固件**，
而这块板子的分区表只有单个 factory 应用分区，没有备用分区可以切换 ——
MicroPython 里没地方安全地写「正在运行的自己」。

所以你把它拖进去时，设备会明确告诉你：

```
这是整机固件 BIN，不是应用更新包。网页 OTA 只能更新程序与界面（.ams 包）；
要整机升级请用 USB 刷写 esp32c3-ams-firmware.bin（C3 板）或 esp32s3-ams-firmware.bin（S3 板）
```

整机升级仍然用（换成你手上的板型）：

```bash
# ESP32-C3
esptool.py --chip esp32c3 --port COM5 write_flash -z 0x0 esp32c3-ams-firmware.bin
# ESP32-S3（42 针）
esptool.py --chip esp32s3 --port COM5 write_flash -z 0x0 esp32s3-ams-firmware.bin
```
</details>

<details>
<summary><b>用 <code>tools/make_update_pack.py</code> 生成的更新包上传后提示「校验失败」</b></summary>

按顺序排查：

1. **上传过程被打断**（手机切后台、WiFi 抖动）→ 会报
   `上传中断（已收到 x/y 字节）`，重传即可。
2. **文件传坏了** → 会报某个文件 `CRC32 不匹配`。重新生成包再传：
   `python tools/make_update_pack.py`。
3. **`python_code/` 里改完代码忘了重新打** → 包里的还是旧内容（这不会报错，
   只是升级后行为没变）。改完代码务必重新生成。
4. 报 `更新包长度不一致` / `清单被截断` → 包本身不完整，重新生成。

> 升级包**不包含** `config.json` / `wifi.dat` / `boot_stat.json`，
> 也不允许包里去覆盖它们（会被拒绝）。所以升级不会丢 WiFi 和打印机配置。
</details>

<details>
<summary><b>AP 能连上，但管理页打不开，串口一直刷 <code>memory allocation failed, allocating 36096 bytes</code></b></summary>

这是**页面太大、被整份读进内存**导致的（已修）。

ESP32-C3 的空闲堆只有几十 KB，而且碎片化严重；`index.html` 有 40KB，
`f.read()` 要一次性拿到连续 40KB —— 直接失败。**更坑的是**：原来第二次请求
想复用内存缓存，可是缓存根本没写进去，于是**每个请求都在同一个地方再失败一次**，
页面就永远打不开，串口一直刷同一行错误。

现在改成**分块流式发送**：`os.stat()` 取文件长度写进 `Content-Length`，
正文每次只读 1KB（`FILE_CHUNK`）读一块发一块，单次最大分配 1KB，
也不再有第二份 `.encode()` 拷贝；块与块之间 `await` 让步，发页面时换料主循环
和状态灯不会被饿死。

排查步骤：

1. 刷最新的 `esp32c3-ams-firmware.bin`（地址 `0x0`，整片）。
2. 看串口第一行：`配置页面 index.html（42088 字节）按 1024 字节分块发送，空闲内存 xxx 字节`。
   **空闲内存低于 20KB 就不正常**（说明别处有泄漏），把这行日志发出来。
3. 页面打开后看「上电诊断」卡片里的**空闲内存**一行，正常是几十 KB。

> 顺带说一句：以后只要在串口看到「…（空闲内存 xxx 字节）」，就先看这个数字 ——
> 所有请求异常都会带上它，OOM 类问题一眼就能判断余量。
</details>

<details>
<summary><b>网页能打开，但「运行状态」全是 <code>-</code>、通道和硬件调试一直「加载中」</b></summary>

**这是 `/status` 接口自己 OOM 了**（已修）。

这个现象很有迷惑性：页面本身是分块流式发的，所以能打开；但页面上的数据全靠
`/status` 这一个接口，它一失败，所有卡片就只剩下默认的 `-`。

原因是 `/status` 里塞了 `boot_safety.report` —— 一整段中文接线表。
`ujson.dumps` 之后体积要翻好几倍，`send_response` 再 `.encode()` 复制一份，
空闲堆只剩 20KB 的板子必然失败，而且**每 2 秒轮询一次就失败一次**。

现在：

- `report` 不再进 JSON，`problems` 每条截断到 120 字，SSID 最多给 12 个
- 字符串响应改成「切块 → 逐块 encode → 逐块发」，峰值只有 512 字符
- 每个字段单独兜底，某一个取不到值时它自己变 `-`，不会连累整个接口

如果还遇到，串口/日志面板里会有 `状态字段 xxx 取值失败: ...`，把那一行发出来即可定位。
</details>

<details>
<summary><b>点「保存并连接」提示 404，或者提示连不上、配置也没存下来</b></summary>

两个独立的问题，都修了：

**① 提示 404** —— 读请求的函数看到 `\r\n\r\n` 就返回了，而 JSON 请求体往往在
**下一个** TCP 段里。服务端解析出 `None`，路由条件不成立，就落到了 404 分支。
所以你看到的「404」其实不是接口不存在，只是请求体没读到。
现在按 `Content-Length` 把请求体读完；万一还是空的，会回 **400 并写明原因**。

**② 配置存不下来** —— 旧逻辑是「只有 MQTT 当场连上才写 `config.json`」。
可是在 AP 配置模式下根本没联网，MQTT 必然连不上 → 保存永远失败、
配置永远存不下来，重启之后还得重填。

现在改成 **先落盘，再连接**：配置一定写进 `config.json`，连不上只作提示。
页面上「打印机 MQTT 配置」里也能看到「配置是否已保存：已保存 / 尚未保存」。

顺带放宽了校验：只有 **打印机 IP / 序列号 / 访问码** 是必填，
用户名、客户端名、端口留空会自动填 `bblp` / `mqttx_3c73cd31` / `8883`。
</details>

<details>
<summary><b>左侧菜单里的「WiFi 配置」不见了 / 想换 WiFi 怎么办</b></summary>

这是故意的：**WiFi 配置只在配置热点开启时显示**。

- 配网成功之后设备会自动关掉热点，菜单项跟着消失 —— 因为已经连上网了，
  平时根本用不到这个页面
- 想换 WiFi：到「运行状态」页面点 **「打开配置热点」**，手机连上 `AMS_WIFI`
  （密码 `A12345678`）后访问 `http://192.168.4.1`，「WiFi 配置」就会重新出现
- 换完之后点「连接这个 WiFi」，热点会自动关掉，菜单项又消失

> 手机连着家里的 WiFi 时是访问不到 `192.168.4.1` 的（不同网段），
> 需要先把手机切到 `AMS_WIFI` 热点。
</details>

<details>
<summary><b>AP 模式下串口一直在刷「未连接wifi」/「MQTT 未连接，尝试重连」</b></summary>

配置热点模式下 STA 本来就没连上路由器，反复去建 MQTT 是白费功夫。
现在 `run_ams_loop` 会先判断 WiFi：没连上就退避 30 秒、日志降频，
只打印 `WiFi 未连接，暂不重连 MQTT（等待配网）`。
连上 WiFi 之后才会按原来的节奏（10 秒一次、每 6 次打一条）重连。
</details>

<details>
<summary><b>为什么开机后 WiFi 列表是空的</b></summary>

因为**开机不再扫描 WiFi** 了（`scan()` 会阻塞 1.5~3 秒，拖慢开机和网页响应）。
列表由页面加载时触发的一次按需扫描填充，或者点「重新扫描」按钮手动刷新。
已保存的 WiFi 会直接连接，不需要出现在列表里。
</details>

<details>
<summary><b>想从 4 通道扩展到 8 通道</b></summary>

1. 在 `hardware_config.py` 里把 `CLUTCH_PINS` 扩成 8 个 GPIO，
   `LIMIT_SWITCH_PINS` 同步补齐长度。
2. `motor_clutch.FilamentMotorBus` 本身支持任意路数，不用改。
3. 注意 ESP32-C3 的干净引脚有限，8 路需要用到 strapping 脚
   （GPIO2/GPIO8/GPIO9）或放弃 USB（GPIO18/19），见
   [ESP32-C3 引脚约束](#esp32-c3-引脚约束)。
4. 8 路离合的供电要单独规划，建议用带使能的驱动模块逐路供电。
</details>

---

## 附录 A：部分 MQTT 命令说明

以下代码来自
[ha-bambulab/custom_components/bambu_lab/pybambu/commands.py](https://github.com/greghesp/ha-bambulab/blob/main/custom_components/bambu_lab/pybambu/commands.py)

```python
"""MQTT Commands"""
# 开灯
CHAMBER_LIGHT_ON = {
    "system": {"sequence_id": "0", "command": "ledctrl", "led_node": "chamber_light", "led_mode": "on",
               "led_on_time": 500, "led_off_time": 500, "loop_times": 0, "interval_time": 0}}
# 关灯
CHAMBER_LIGHT_OFF = {
    "system": {"sequence_id": "0", "command": "ledctrl", "led_node": "chamber_light", "led_mode": "off",
               "led_on_time": 500, "led_off_time": 500, "loop_times": 0, "interval_time": 0}}
# 设置速度
SPEED_PROFILE_TEMPLATE = {"print": {"sequence_id": "0", "command": "print_speed", "param": ""}}
# 获取版本
GET_VERSION = {"info": {"sequence_id": "0", "command": "get_version"}}
# 恢复打印
PAUSE = {"print": {"sequence_id": "0", "command": "pause"}}
# 暂停打印
RESUME = {"print": {"sequence_id": "0", "command": "resume"}}
# 停止打印
STOP = {"print": {"sequence_id": "0", "command": "stop"}}
# 获取所有
PUSH_ALL = {"pushing": {"sequence_id": "0", "command": "pushall"}}
# 开始推送
START_PUSH = {"pushing": {"sequence_id": "0", "command": "start"}}
# 发送 gcode
SEND_GCODE_TEMPLATE = {"print": {"sequence_id": "0", "command": "gcode_line", "param": ""}}
# param = GCODE_EACH_LINE_SEPARATED_BY_\n

# X1 only currently
GET_ACCESSORIES = {"system": {"sequence_id": "0", "command": "get_accessories", "accessory_type": "none"}}
```

本项目用到的换料相关命令定义在 `python_code/bambu/bambu_commands.py`：

```python
bambu_resume = '{"print":{"command":"resume","sequence_id":"1111111"},"user_id":"1"}'          # 继续打印
bambu_unload = '{"print":{"command":"ams_change_filament","curr_temp":220,...}}'              # 退料
bambu_load   = '{"print":{"command":"ams_change_filament","curr_temp":220,...}}'              # 进料
bambu_done   = '{"print":{"command":"ams_control","param":"done",...}}'                       # 确认进料完成
banbu_start  = '{"pushing": {"sequence_id": "1111111", "command": "pushall"}}'                # 获取设备信息
START_PUSH   = '{ "pushing": {"sequence_id": "1111111", "command": "start"}}'                 # 开始推送
```

---

## 附录 B：G-code 参考

### 擦拭插头

```gcode
M400
M106 P1 S178        ; 开启风扇
M400 S3             ; 设置打印速度
G1 X-3.5 F18000     ; 移动打印头进行擦拭
G1 X-13.5 F3000
G1 X-3.5 F18000
G1 X-13.5 F3000
G1 X-3.5 F18000
G1 X-13.5 F3000
M400                ; 等待所有动作完成
M106 P1 S0          ; 关闭风扇
```

### 切割材料

```gcode
G1 X180 F18000      ; 跑到切割待机位
G1 X200 F300        ; 进行切割
G1 X-13.5 F6000     ; 跑回冲刷区
G1 E-5 F100         ; 退出 5mm 的丝料
```

### 设置安全距离

```gcode
G91                 ; 相对定位
G1 Z10 F600         ; 将 Z 轴提升 10mm，避免与打印物接触
G90                 ; 绝对定位
```

### 挤出机

```gcode
M109 S[nozzle_temperature_range_high]   ; 设置喷嘴温度
M82                                     ; 激活绝对挤出模式
M83                                     ; 激活相对挤出模式
G92 E0                                  ; 重置挤出量
```

### 风扇

```gcode
M106 P1 S0          ; 关闭风扇 1（散热风扇）
M106 P1 S255        ; 风扇开到最大
```

### 切料软件配置

```gcode
M73 P101 R[next_extruder]
```

---

## 致谢与许可

- 上游项目：[YBA-AMS](https://github.com/yuanbao-yu/YBA-AMS)
- MQTT 命令参考：[greghesp/ha-bambulab](https://github.com/greghesp/ha-bambulab)
- 许可证：[MIT](./LICENSE)

第三方组件：

| 组件 | 用途 | 许可证 |
| --- | --- | --- |
| [MicroPython](https://micropython.org/) 官方固件 | ESP32-C3 运行时（构建时下载，未修改） | MIT |
| [littlefs](https://github.com/littlefs-project/littlefs) 2.8.0 | 生成设备文件系统镜像（构建时下载使用） | BSD-3-Clause |
| [umqtt.simple](https://github.com/micropython/micropython-lib) | MQTT 客户端，已纳入 `python_code/umqtt/` | MIT |

> 本项目为个人 DIY 项目，涉及对打印机的远程控制与自研送料机构。使用前请确认
> 你了解相关风险，尤其是电磁离合的驱动电路与供电设计。因硬件设计不当导致
> 的设备损坏不在本项目责任范围内。

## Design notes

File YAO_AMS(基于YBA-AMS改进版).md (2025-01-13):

# YAO_AMS(基于YBA-AMS改进版)

83bc5bb869cc607bf0961988dcada98

### 简介

	本项目是适用于拓竹打印机的ams自动换料系统，基于YBA-AMS的版本进行改进。

   			1. 使用esp32为主控。使用mircopython进行开发，且使用TCP - web进行ams与操作人可视化交互。mqtt 与 拓竹打印机连接。且使用接口进行获取数据，可以方便二次开发。
   			2. 目前已经测试4通道，主板提供扩展接口,最多支持8通道。
   			3. 在A1mini上进行测试。只能使用0.1.03.01.00以下的版本固件。
   			4. 每次换料时间为1分钟半左右（从停止打印到开始打印，包括冲刷时间）。
   			5. 改进缓冲区，让远程送料不易卡住

### 使用说明

#### 初次配置

   1. 先连接主板的热点进行初始配置。热点名称为 AMS_WIFI,密码为;123456.连接后先进行主板wifi连接，与打印机同一个网络下。

      连接成功，再进行mqtt连接，输入对应的信息进行连接。之后就是料盘配置，为每一料盘设置样式，方便区分。页面如下:

      

2. 配置完成后，电脑可以断开热点连接，进行wifi连接，后续需要修改配置的可以，输入页面最上面的ip地址进行访问，修改配置等。

3. 修改下Bambu Studio的换料G-code.修改内容再g-code下

#### 打印时候配置

1. 打印前需要确认mqtt是否连接。主板上蓝灯为长亮为mqtt已经连接，闪烁的话为wifi已经连接，一会长亮，一会闪烁则为可以进行多色打印。

2. 进行打印，配置打印颜色对应的通道id就完成了。配置文件是可持久化的，主板断开电源重新启动，数据还是原先配置的。打印通道对应示例如下：



### 部分命令说明

以下代码来自[ha-bambulab/custom_components/bambu_lab/pybambu/commands.py at main · greghesp/ha-bambulab (github.com)](https://github.com/greghesp/ha-bambulab/blob/main/custom_components/bambu_lab/pybambu/commands.py)

```python
"""MQTT Commands"""
# 开灯
CHAMBER_LIGHT_ON = {
    "system": {"sequence_id": "0", "command": "ledctrl", "led_node": "chamber_light", "led_mode": "on",
               "led_on_time": 500, "led_off_time": 500, "loop_times": 0, "interval_time": 0}}
# 关灯

CHAMBER_LIGHT_OFF = {
    "system": {"sequence_id": "0", "command": "ledctrl", "led_node": "chamber_light", "led_mode": "off",
               "led_on_time": 500, "led_off_time": 500, "loop_times": 0, "interval_time": 0}}
# 设置速度
SPEED_PROFILE_TEMPLATE = {"print": {"sequence_id": "0", "command": "print_speed", "param": ""}}
# 获取版本
GET_VERSION = {"info": {"sequence_id": "0", "command": "get_version"}}
# 恢复打印
PAUSE = {"print": {"sequence_id": "0", "command": "pause"}}
# 暂停打印
RESUME = {"print": {"sequence_id": "0", "command": "resume"}}
# 停止打印
STOP = {"print": {"sequence_id": "0", "command": "stop"}}
# 获取所有
PUSH_ALL = {"pushing": {"sequence_id": "0", "command": "pushall"}}
# 开始推送
START_PUSH = { "pushing": {"sequence_id": "0", "command": "start"}}
# 发送gcode
SEND_GCODE_TEMPLATE = {"print": {"sequence_id": "0", "command": "gcode_line", "param": ""}} # param = GCODE_EACH_LINE_SEPARATED_BY_\n

# X1 only currently
GET_ACCESSORIES = {"system": {"sequence_id": "0", "command": "get_accessories", "accessory_type": "none"}}
```

### 部分G-code说明

#### 擦拭插头

```python
M400
M106 P1 S178; 开启风扇
M400 S3; 设置打印速度
; 移动打印头进行擦拭
G1 X-3.5 F18000
G1 X-13.5 F3000
G1 X-3.5 F18000
G1 X-13.5 F3000
G1 X-3.5 F18000
G1 X-13.5 F3000
M400  ; 等待所有动作完成
M106 P1 S0  ; 关闭风扇

###########
M400 S3;\nG1 X-3.5 F18000;\nG1 X-13.5 F3000;\nG1 X-3.5 F18000;\nG1 X-13.5 F3000;\nG1 X-3.5 F18000;\nG1 X-13.5 F3000; \nM400;
```

#### 切割材料

```python
G1 X180 F18000 # 跑到切割待机位
G1 X200 F300	# 进行切割
G1 X-13.5 F6000		# 跑回冲刷区
G1 E-5 F100	# 退出5mm的丝料
```

####  设置安全距离

```python
; 移动打印头到安全位置 
G91  ;相对定位 
G1 Z10 F600  ;将Z轴提升10mm，避免与打印物接触
G90  ; 绝对定位
```

#### 挤出机

```python
M109 S[nozzle_temperature_range_high]  ; 设置喷嘴温度
M82  ; 激活绝对挤出模式
M83  ; 激活相对挤出模式
G92 E0              ; 重置挤出量
```

#### 风扇

```python
M106 P1 S0;关闭风扇1（扇热风扇）
M106 P1 S255:风扇开到最大
```

#### 切料软件配置

```python
M73 P101 R[next_extruder]
```

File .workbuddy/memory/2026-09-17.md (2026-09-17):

# 2026-09-17

## 刷机后无 AP：根因确认与修复（延续 09-16 晚 22:30 的串口排查）

- 用户刷的是 CI 固件（release latest = 09e749b「说明」，用户自己 push 的），
  板子起不来热点，串口报 `RuntimeError: Wifi Unknown Error 0x0101`，
  崩在 network_model.py:76 建 WLAN 那一步。
- **根因：0x0101 = ESP_ERR_NO_MEM**（MicroPython 的 WiFi 错误表只认
  0x3001~0x300E，落在外就显示 Unknown Error，非常误导）。
  esp_wifi_init() 要一次性申请约 24KB **连续**堆内存；main.py 先
  `from AMS_WEB import main_task` 把应用加载进堆（吃 ~107KB、切碎堆），
  剩 92KB 空闲也拼不出连续 24KB → 失败。
- **修法**：main.py 顶部、import 应用之前先 `network.WLAN(AP_IF)` +
  `network.WLAN(STA_IF)`。空堆一次成功；之后再调只花 16 字节（对象复用）。
  串口实测：空堆 ~200KB → 成功；WiFi 总代价 AP 24,576B + STA 16B。
- 桌面自测 116/116 过；提交 **6288725**（纯增量，原逻辑原样保留）。
- **板子早上没插**（枚举不到任何串口/CH343）。推板脚本已备好：
  `%TEMP%\push_main.ps1` —— Ctrl-C 抢 REPL → 粘贴模式 base64 写入
  main.py → SHA256 回读校验 → RTS 复位 → 抓 40 秒启动日志 → 自动判定
  （失败关键字 0x0101/Traceback；成功关键字 配置热点已打开/AMS_WIFI/192.168.4.1）。
  板子插上后一条命令完成验证。
- 待办：①板子插上跑 push_main.ps1，确认 AMS_WIFI 出现；②提醒用户 push
  6288725 触发 CI 重编固件（否则下次整烧的还是坏 main.py）。
- 顺手清了根目录临时探针 `_bin_probe.py` / `_boot_sim.py`。
- 串口工具链（都在 %TEMP%，复用价值高）：`mpy_paste.ps1`（粘贴模式执行
  ASCII 代码）、`ams_ctrlc2.ps1`（RTS 复位 + 持续 Ctrl-C 抢干净 REPL）、
  `ams_serial.ps1`（被动监听 + 复位抓日志）。pyserial 没装，全靠 .NET
  SerialPort。

## 下午：重启循环修完后，用户反馈「连接 AP 失败」——定位为硬件侧（能收不能发）

启动链已经完全干净（0 复位 / 0 traceback / 0 OSError，热点 0.57s 起来、
Web 2.76s 起来，桌面自测 116/116，提交 51ec834），但手机/电脑**搜不到
AMS_WIFI**。逐层排除，最后确认是**板子射频发射侧的问题，软件无解**：

| 测什么 | 结果 |
|---|---|
| 板子自报 AP 状态 | `active=True`、`essid=AMS_WIFI`、`authmode=3`、`channel=1`、`hidden=False`、`max_clients=10`、`ifconfig=192.168.4.1` —— **全对** |
| 板子自己的 STA `scan()`（AP 关掉时） | **扫到 14 个网**，xiaomi2 才 -40dBm → **RX 正常、天线正常** |
| 板子的 STA 连路由器 | 连上 xiaomi2，DHCP 拿到 192.168.2.153 → **TX 也正常** |
| Windows `netsh wlan show networks` | 反复扫，AMS_WIFI **0 命中**（同批能扫到 2.4G 的 xiaomi2 / FAST_2.4G） |
| Windows 主动 `netsh wlan connect name=AMS_WIFI` | 请求"成功"但仍停在原网络，拿不到 192.168.4.x → 定向 probe 也没回应 |
| 擦 NVS(0x9000+0x6000) + phy_init(0xf000+0x1000) | 无效 |
| **整片 erase_flash + 只烧官方纯净固件**（无任何应用代码） | 裸 AP 依然 0 命中 → **彻底排除软件/配置/应用** |
| 开放网络 / WPA2 / 先 config 后 active / 信道 1·6·11 / 降功率到 2dBm | 全部无效（降功率那次 1/3 是误报，A/B/A 各 8 次复测均为 0） |
| eFuse summary | 正常，无 TX 功率限制迹象 |

- 一个耐人寻味的旁证：`ap.config(channel=6)` 之后 `ap.config("channel")`
  **永远读回 1**（MicroPython 读的是 `esp_wifi_get_channel`，即射频实际
  信道）—— 说明 AP 的射频层其实没有真正跑起来，但 `active(True)` 没报错。
- 芯片：ESP32-C3 QFN32 rev v0.4，40MHz，MAC 9c:cc:01:60:02:d4（esptool 认）。

### 顺带确认：STA + 网页这条路是通的
- 重启日志里出现过 `配置页面 index.html（65607 字节）按 1024 字节分块发送`
  —— 有客户端真的把首页取走了（我的电脑连 5G、板子连 2.4G，疑似路由器
  做了频段/AP 隔离，所以我这边 ping/HTTP 都打不通，**用户侧能通**）。
- ping 不通是正常的：MicroPython 的 lwIP **不回 ICMP**，不能用 ping 判定
  板子在不在线。
- 我这边 `Invoke-WebRequest /` 报"连接被意外关闭"、`/index.html` 返回
  **404** —— 404 说明 HTTP 服务确实在响应。

### 产出
- 新增 `tools/serial_provision.ps1`：**串口配网**，绕开坏掉的 AP，直接把
  `SSID;密码` 写进 wifi.dat 让板子连路由器（密码不落盘、日志打码）。
  用法：`.\tools\serial_provision.ps1 -Port COM22 -SSID xxx -Password yyy`。
- 新增 `%TEMP%\pushall.ps1`：整片擦除后**全量回推** 19 个文件（含新建
  `bambu/` 目录），逐行 base64 写入 + 每个文件 SHA256 回读校验。本次
  一次通过（ALL_FILES_OK），板子已完全恢复。
- 注意：排查中我整片擦过 flash，并已用上面的脚本把应用全量推回；
  wifi.dat 里现在写着 xiaomi2（我通过串口写入的），板子会自动连它，
  IP 192.168.2.153。

### 给用户下一步（等他确认）
1. 手机贴到板子 10cm 内搜 AMS_WIFI（排除"功率极低"）。
2. 换 USB 口 / 短线 / 外接 5V 电源（boot.py 自检一直在提示欠压复位，
   供电嫌疑大）。
3. 看模块型号：若带 IPEX 座且没插外接天线 → 就是它。
4. 都不行 → 换一块 ESP32-C3 模块对比。

## 傍晚：「网页打不开」根因 = C3 内存不够（不是网络问题）+ 双开发板改造

用户强烈反馈：加了 OTA 功能之后网页彻底打不开（之前"只是慢但能用"），
要求「增加 ESP32S3 42 针、同时编译两块板的固件、IO 冲突就拆成两个配置文件、
编译自动调用对应配置、把 S3 剩余可用 IO 全部引出」。

### 1) 「网页打不开」的真正根因（两层，第二层才是致命的）

| 层 | 现象 | 结论 |
|---|---|---|
| 表层 | ESP32 默认 WiFi modem-sleep（`pm=1`），持续传输时周期性休眠 → STA 掉线，串口刷 `ECONNABORTED` | `sta.config(pm=0)` 关掉省电后，空应用下 65KB 页面 5.7 秒发完 |
| **根因** | **C3 只有 400KB SRAM**。不加载应用时空闲堆 149KB；**加载应用后只剩约 60KB**，最大连续块更小。WiFi 驱动收发时要动态申请**连续**缓冲 → 申请不到就 `OSError(113)`，重传 9.4 秒后放弃、射频卡死只能复位 | `probe_sf5`（app 已加载、阻塞式 accept、无 asyncio）仍 `ERR OSError(113) free=60256`；`probe_mem_app` 显示光 `ota_update` 就吃 15968B |

→ 加 OTA 之后应用变大，把「偶发」推成「必然」。**pm=0 是必要的，但在 C3 上
不充分**；真正的解法是换 S3。pm=0 与「发送后 drain 再关连接」两处修复已保留
（对 S3 也有益）。

### 2) 双开发板改造（提交 b361fba，本地提交，未 push）

架构：**同一套业务代码 + 两套引脚表 + 编译期写死板型**

- `python_code/board_c3.py` / `board_s3.py`：只描述"这块芯片哪些脚能用"
  （默认接线 / 保留脚 / strapping / 安全输出脚 / 剩余可用 IO）
- `python_code/hardware_config.py`：只剩「选板型 + 业务参数 + 上电自检」，
  导出所有引脚常量，上层代码一行不改
- 板型优先级：**编译期 `board_select.py`（BOARD="c3"/"s3"/"auto"）** >
  现场 `board_override.py`（可覆盖任意引脚，不进 git）> `os.uname().machine`
  识别（认不出按 C3 并提示）

S3 默认接线：电机 4/5、离合 6/7/8/9（**全干净脚**）、状态灯 2。
C3 上 4 号离合只能挤在 strapping 的 GPIO3（带病运行），S3 没这个问题。
S3 剩余可用 IO **全部列出**：18 只干净脚（含到位开关推荐的 11~14）
+ 4 只空闲 strapping 脚（0/3/45/46）。

构建：
- `python tools/build_mpy.py`（默认 `--board both`）→ `dist/c3/`、`dist/s3/`
  + `dist/esp32c3-ams-mpy.zip`、`dist/esp32s3-ams-mpy.zip`；
  编译时生成 `board_select.py`，**部署说明里直接写出该板实际接线与剩余可用脚**
- `python tools/make_firmware_bin.py --board c3|s3 --chip esp32c3|esp32s3`
  → 暂存源码目录（`dist/_work/src-<board>`）里写入 `board_select.py` 再打包，
  不污染版本库；产物默认 `dist/<芯片>-ams-firmware.bin`
- `python tools/make_update_pack.py --board keep|c3|s3|auto`，默认 keep
  （OTA 只换业务代码，不动设备原有板型设置）
- CI 改成 matrix：C3/S3 各自的 .mpy 包与单文件固件一起构建、一起发布

关键实测数据（已核对）：
- **官方固件分区表**：C3 `vfs @0x200000 size 2MB`（总 4MB）；
  S3 `vfs @0x200000 size 6MB`（**总 8MB → S3 单文件固件必须烧在 8MB 及以上模组**）
- S3 官方固件 `ESP32_GENERIC_S3-20240602-v1.23.0.bin`，
  SHA256 `b91080af2e9b78bad4308f98bb6187567cae24ed77cd7f48ef99b47af3ef0555`
  （C3 那份还是 `8058b7d6…`，没变）

测试：新增 8 项（两份引脚表都校验、板型优先级、S3 剩余 IO 数量）→ **124/124 全绿**。

### 环境备忘
- mpy-cross 1.23.0（mpy v6.3）已装在隔离环境
  `C:\Users\lkfcs\.workbuddy\binaries\python\envs\default\Scripts\python.exe`，
  用这个解释器跑构建/自测即可
- **本机没有 gcc**，编译不出 `tools/build/lfs_mkfs`，所以单文件固件只能在 CI 里出；
  本地已验证分区解析 + `stage_source` 板型下发逻辑（用真实官方固件跑的）
- 官方固件缓存在 `dist/_cache/`（C3 + S3 两份都在），离线构建可直接复用
- ⚠️ **Bash 工具在这台机器上基本不可用**（无 coreutils：`dirname`/`head`/`tail`/`cat`
  全没有）；`git` 和 `python` 能用。PowerShell 工具可靠，但**标准输出会被吞**，
  要拿结果就写文件再用 Read 读。cmd.exe 被安全策略禁用。

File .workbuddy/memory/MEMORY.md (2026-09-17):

# YAO_AMS 项目长期备忘

## 项目定位

适配拓竹（Bambu Lab）打印机的 AMS 自动换料系统，ESP32-C3 / **ESP32-S3（42 针）**
双平台 + MicroPython。
上游是 YBA-AMS，本项目主要差异是执行机构改为「1 个共享直流电机 + 4 路电磁离合」。
GitHub: https://github.com/liu-85/esp-ams （remote origin，main 分支）

## 双开发板架构【重要：改引脚前先读这一段】

同一套业务代码 + **两套引脚表** + 编译期写死板型。

- `python_code/board_c3.py` / `board_s3.py`：只描述"这块芯片哪些脚能用"
  （默认接线 / 保留脚 / strapping / SAFE_OUTPUT_PINS / SPARE_PINS）。**改接线改这里**
- `python_code/hardware_config.py`：选板型 + 业务参数（时序、降级时长）+ 上电自检，
  导出全部引脚常量。上层代码只写 `from hardware_config import MOTOR_PIN_IN1`，一行不改
- `python_code/board_select.py`：**构建产物，不进 git**，内容就一行 `BOARD = "c3"/"s3"/"auto"`
- `board_override.py`：可选现场覆盖文件（板子上放一个即可改引脚，不进 git）

板型优先级：编译期 board_select.py > board_override.py > `os.uname().machine`
（认不出按 C3 处理并提示）。

引脚差异（其余相同）：
| | 电机 | 离合 1~4 | 状态灯 |
|---|---|---|---|
| C3（GPIO 上限 21） | 4/5 | 6, 7, 10, **3**（3 是 strapping，带病运行） | 2 |
| S3（GPIO 上限 48） | 4/5 | 6, 7, 8, 9（**全干净**） | 2 |

S3 剩余可用 IO（未装到位开关时）：**18 只干净脚**
`1,10,11,12,13,14,15,16,17,18,21,38,39,40,41,42,47,48`
+ 4 只空闲 strapping 脚 `0,3,45,46`。S3 保留脚：19/20(USB)、26~32(Flash)、
33~37(八线 PSRAM)、43/44(UART0)。S3 的 strapping：0/3/45/46。

**为什么推荐 S3**：C3 只有 400KB SRAM，应用加载后空闲堆仅约 60KB，
WiFi 驱动收发要申请**连续**缓冲 → 传 40KB+ 的 index.html 会 `OSError(113)`、
射频卡死只能复位（见下）。加 OTA 后应用变大，问题从「偶发」变「必然」。

## 硬件约定

- **具体引脚号在 `board_c3.py` / `board_s3.py` 里，不在 hardware_config.py**
  （hardware_config 只负责选板型 + 业务参数）
- 共享电机 H 桥：IN1=GPIO4 方向 1 进料，IN2=GPIO5 方向 -1 退料（两块板相同）
- 电磁离合 1~4：C3 = 6/7/10/3，S3 = 6/7/8/9，高电平吸合
- 状态 LED：GPIO2（两块板相同）
- **硬性约束：任何时刻最多 1 路电磁离合吸合**，由
  `motor_clutch.FilamentMotorBus` 四重机制强制（前置断开 / 吸合前复核 /
  直接调用拦截 / 运行期 assert_single）
- ESP32-C3 禁用引脚：11~17（内置 Flash）、18/19（USB）、20/21（UART0）；
  2/8/9 是 strapping，谨慎使用
- **WiFi 必须关省电**：ESP32 默认 `pm=1`（modem sleep），持续传输时会周期性
  休眠 → STA 掉线（串口报 `ECONNABORTED` / `ECONNRESET`），表现是"网页传一半
  就断"。main.py 第 0 步与 network_model.__init__ 都已 `sta/ap.config(pm=0)`，
  而且**必须在干净堆上做**（它动 WiFi 配置，同 swcith_ap 那类 0x0101 陷阱）。
- **C3 传大文件会失败是内存问题，不是网络问题**：应用加载后空闲堆仅约 60KB，
  WiFi 驱动要申请**连续**缓冲 → `OSError(113)`（EHOSTUNREACH）→ 重传约 9 秒
  放弃 → 射频卡死只能复位。ping 通、TCP 连不上就是这个症状。
  **根治办法是换 ESP32-S3**；C3 上只能靠 .mpy 省内存勉强跑。
- **WiFi 驱动必须抢在应用加载之前初始化**：`network.WLAN()` 第一次调用
  要一次性申请约 24KB **连续**堆；应用 import 之后堆碎片化就抢不到，
  报 `Wifi Unknown Error 0x0101`（= ESP_ERR_NO_MEM，在错误表外）。
  main.py 顶部已前置 `WLAN(AP_IF)+WLAN(STA_IF)`，之后再调只花 16 字节
  （对象复用）。**往 main.py 前面加 import 时，别把这段挪到后面。**

### 「干净堆预分配」总规则【本项目最容易复发的一类 bug】

MicroPython 的 GC **不做压缩**。应用 import 完，空闲还有 64KB，
但**最大连续块只剩 3,584 字节**，`gc.collect()` 也只多合出 2KB。
于是**凡是"要一大块连续内存、且只在启动时做一次"的操作，都必须抢在
应用加载之前做完**，否则要么抛 `0x0101`，要么**直接硬复位（无 traceback）**。

main.py 的阶段划分就是这条规则的产物，不要在中间插 import：
0. 建 AP/STA 对象 + `sta.active(True)` 真开射频（AP 已起时 STA 只花 48 字节）
0.5 `auto_connection()`，失败才 `swcith_ap(1)` 开热点
0.6 `boot_resources.prepare_web_server()` 预建 `:80` 监听 socket
   然后才 `import AMS_WEB`

已确认会踩的同源坑（都修了，别改回去）：
- `network_model.__init__` **不许 `active(False)`**：AMS_WEB→AMS→Bambu_mqtt_cliet
  这条继承链会让 `__init__` 在 main_task 里再跑一次，把刚开好的口关掉
- `swcith_ap(1)` 必须**幂等**：热点已 active 时**绝不能再 `config()`** ——
  实测碎堆上 `ap.config(essid/password/authmode)` 任一参数都抛 0x0101
  （`active()`、`ifconfig()` 都正常，`active(True)` 重复调是 no-op）
- 运行期开关热点仍有风险：配网成功 `swcith_ap(0)` 安全，之后想再开热点
  会在碎堆上 `esp_wifi_start` → 复位。要换 WiFi 请重启走第 0.5 步

## 代码约定

- 所有硬件参数只在 `hardware_config.py` 里改，业务代码不写死引脚
- 离合操作只能通过 `bus.run()` / `bus.hold()`，不直接写 Clutch 的引脚
- 复合动作必须用 try/finally 保证「停电机 + 断开全部离合」
- `boot.py` / `main.py` 必须保持 `.py`，不能编译成 `.mpy`
- `config.json` / `wifi.dat` 含密码，已在 .gitignore 里，不要提交
- **同一文件不要并行发两个 Edit**，会互相覆盖丢改动（USER.md 明确要求）

## 当前运行模式

未安装到位开关（`LIMIT_SWITCH_PINS = (None,)*4`），程序走降级模式：
- `now_filament()` 不探测，直接读 `config.json` 里的 `filament_current`
  → **不要手动插拔料盘**，否则记录与实际不一致
- 送料按时间推进，`NO_LIMIT_LOAD_MS` / `NO_LIMIT_RETRACT_MS` 需实测调整

## 已知硬件问题：AP 热点发不出信号（2026-09-17 确诊，软件无解）

- 现象：启动日志一切正常（`配置热点已打开: AMS_WIFI`，0.57s 就起来），
  但**任何客户端都搜不到这个热点**。软件状态全对（active/essid/authmode/
  channel/hidden/ifconfig 都对），就是不发 beacon。
- 已排除（都实测过）：应用代码、**整片 erase_flash 后只烧官方纯净固件**
  依然如此；擦 NVS + phy_init 无效；开放/WPA2、config 前后顺序、信道
  1/6/11、TX 功率降到 2dBm 全部无效；eFuse 正常。
- 对照组（说明射频本身是好的）：关掉 AP 后 STA `scan()` 能扫到 14 个网
  （最近的 -40dBm），STA 也能连上路由器拿 IP。
- 旁证：`ap.config(channel=6)` 之后 `ap.config("channel")` 永远读回 1，
  说明 AP 的射频层根本没真正起来，只是 `active(True)` 没报错。
- 结论：板子射频发射侧（天线/PA/供电）有问题。**排查方向：手机贴 10cm
  搜 → 换 USB 口/短线/外接 5V → 看模块是否有 IPEX 座没插天线 → 换模块。**
  项目自带的 boot.py 自检一直提示"欠压复位"，供电嫌疑最大。
- 绕行方案：`tools/serial_provision.ps1` —— 串口直写 wifi.dat 配网，
  让板子走 STA 连路由器，不依赖热点。
- ⚠️ **板子 ping 不通是正常的**（MicroPython 的 lwIP 不回 ICMP），
  别用 ping 判断板子在不在线，用 HTTP 或看串口日志。

## 常用命令

```bash
python tests/run_tests.py      # 桌面自测，无需板子（当前 124 项）
python tools/build_mpy.py      # 默认 --board both：两块板各一个包（dist/c3、dist/s3）
python tools/build_mpy.py --board c3|s3|auto   # 只编一个板型
python tools/make_firmware_bin.py --board c3|s3 --chip esp32c3|esp32s3 \
    --firmware-url <官方固件> --out dist/<芯片>-ams-firmware.bin
python tools/make_update_pack.py [--board keep|c3|s3|auto]   # 网页 OTA 的 .ams 包
```

`mpy-cross` 版本必须与板子固件一致，当前 CI 用 1.23.0（mpy v6.3）。
本机已装在隔离环境
`C:\Users\lkfcs\.workbuddy\binaries\python\envs\default\Scripts\python.exe`，
用这个解释器跑构建/自测。**本机没有 gcc**，单文件固件只能在 CI 里出。

官方固件缓存于 `dist/_cache/`。两个芯片的 vfs 分区都是 `0x200000` 起，
但大小不同：**C3 = 2MB（整片 4MB）**，**S3 = 6MB（整片 8MB）**。
→ **S3 单文件固件必须烧在 8MB 及以上 Flash 的模组**（N8R8 / N16R8 满足）。
S3 官方固件 `ESP32_GENERIC_S3-20240602-v1.23.0.bin`
SHA256 `b91080af2e9b78bad4308f98bb6187567cae24ed77cd7f48ef99b47af3ef0555`；
C3 那份是 `8058b7d6eb55f8124fbdcc797e2e8b39ae947a18df635567e02c8786874c04fd`。
分区表由脚本从官方固件里解析，不写死偏移。

## 单文件固件（一键烧录）约定【重要】

- 产物 `dist/<芯片>-ams-firmware.bin` = 官方固件(0x0) + littlefs 镜像(0x200000)，
  C3 共 4MB、S3 共 8MB，`esptool write_flash 0x0` 一把烧完，设备开机即跑。
- 构建时会**先把源码拷到 `dist/_work/src-<board>/` 暂存目录**，在那里写入
  按板型生成的 `board_select.py`，再打包 —— 不往版本库的 python_code/ 写生成物。
- **文件系统必须是 littlefs**：v1.23.0 的 `vfs` 分区 subtype 虽标 0x81，
  实际由 `flashbdev.py` + `inisetup.py` 走 `VfsLfs2`。镜像 block0/1 的
  offset 8 必须有 `"littlefs"` 魔数，否则 `_boot.py` 挂载失败 → 死循环报
  "filesystem appears to be corrupted"。
- **镜像必须用与设备同源的 littlefs 2.8.0 生成**（`tools/lfs_mkfs.c` 链接
  上游源码），不要用 pip 的 littlefs-python 直接生成（它带 2.11，有小文件
  inline 特性，存在兼容风险；只用于反向校验）。
- 升级 MicroPython 时**这些必须同步**：`MICROPYTHON_VERSION`、
  `LITTLEFS_VERSION`、`MPY_CROSS_VERSION`，以及 **CI 里 firmware job 的
  matrix**（两块板各自的固件 URL + SHA256）。
- CI：push 任意分支/ tag 即触发；push main 更新滚动 `latest` 预发布，
  打 `v*` tag 发正式 Release。产物：**两块板各自的** `.mpy` 压缩包 + 固件 BIN。
- `.mpy` 包与固件都带 `board_select.py`，两个通道用同一个约定，不会配置不一致。

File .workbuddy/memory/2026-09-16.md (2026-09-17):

# 2026-09-16

## YAO_AMS：改用「1 共享电机 + 4 路电磁离合」方案

用户需求：检查项目结构、完善说明、加 GitHub Actions 自动编译，并把原来
「每通道 2 个 IO 直驱电机」改成「1 个电机 + 4 路电磁离合」，强制同一时刻
只能 1 路离合吸合，按现有换料逻辑编写。

### 关键发现

- 原 `device_processing.py` 的 `material(18,5)` / `(17,16)` / `(23,22)` / `(21,19)`
  用的是**经典 ESP32 的引脚编号**，GPIO22/23 在 ESP32-C3 上**根本不存在**，
  必须重排。ESP32-C3 可用干净引脚只有 GPIO0/1/3/10（外加放弃 JTAG 的 4~7）。
- `now_filament()` 原来是坏的：`dianji_roll()` 结束时 `stop_roll()` 把两个
  方向脚都置 0，紧接着读 `dianji_top.value()` 永远是 0，所以恒返回 0，
  `exchange_fileament` 里「退料」分支其实从未走到过。本次把
  `dianji_top/bottom` 语义修正为到位开关后逻辑才真正成立。
- 项目**没有 main.py**，boot.py 是空壳，板子上其实没有自动启动入口。已补。
- `config.json` / `wifi.dat` 含 WiFi 密码与打印机访问码，之前没有 .gitignore。

### 最终引脚分配（ESP32-C3）

| 信号 | GPIO |
| --- | --- |
| 电机 H桥 IN1 / IN2 | 4 / 5 |
| 电磁离合 1~4 | 6 / 7 / 10 / 3 |
| 状态 LED | 2（strapping 脚，上电默认高，可用） |

### 交付物

- 新增：`hardware_config.py`、`motor_clutch.py`、`main.py`、
  `tests/mpy_stubs/*`、`tests/run_tests.py`、`tools/build_mpy.py`、
  `.github/workflows/build.yml`、`.gitignore`、`.gitattributes`
- 改写：`device_processing.py`、`AMS_MODEL.py`、`AMS_WEB.py`、`index.html`、`README.md`

### 验证

- `python tests/run_tests.py` → 18/18 通过（含离合互斥、异常必释放、H 桥死区）
- `python tools/build_mpy.py` → 13 个 .mpy 编译成功（mpy-cross 1.23.0, mpy v6.3）
- 已本地提交 `71b70fd`，**未推送**（用户要求只改本地）

### 待办 / 风险

- 未安装到位开关，送料是时间控制模式，`NO_LIMIT_LOAD_MS`(8000) /
  `NO_LIMIT_RETRACT_MS`(6000) 必须按实机实测调整。
- GitHub Actions 里的 `MPY_CROSS_VERSION: 1.23.0` 要和板子固件版本一致，
  否则设备报 `ValueError: incompatible .mpy file`。

---

## YAO_AMS：提交即编译 + 单文件一键烧录固件

用户需求：每次提交自动触发编译；编译后发布**一个**可直接烧录到 ESP32-C3 的
BIN 文件，烧完设备即跑，不需要再单独上传 .py/.mpy。

### 核心原理（踩坑记录）

- ESP32-C3 的官方固件是**从 0x0 起的完整镜像**，所以"单文件"= 官方固件
  (0x0) + 自制 littlefs 文件系统镜像拼接到分区表里 `vfs` 的 offset (0x200000)。
- **致命陷阱**：`_boot.py` 启动时 `vfs.mount(bdev, "/")`，`mp_vfs_autodetect`
  靠 block 0 和 block 1 的 **offset 8 处 `"littlefs"` 魔数**识别文件系统。
  挂载失败会走 `inisetup.check_bootsec()`，首扇区非 0xFF 就打印
  "The filesystem appears to be corrupted" 并**死循环**，永远跑不到用户代码。
- 官方 C3 v1.23.0 分区表：nvs@0x9000(24K)、phy_init@0xf000(4K)、
  factory@0x10000(1984K)、vfs@0x200000(2M, subtype **0x81** 但实际是 **littlefs2**，
  不是 FAT)。
- **版本必须对齐**：v1.23.0 内置 littlefs `LFS2_VERSION=0x00020008`(2.8)。
  pip 的 `littlefs-python` 0.19 自带 littlefs **2.11**。最终决定用**设备同源
  2.8.0 上游源码**自己编译工具生成镜像。
- 本地无 gcc → 用 TinyCC 0.9.27 win64 编译 `tools/lfs_mkfs.c` 做本地验证；
  CI 用 ubuntu 自带 gcc。

### 交付物

- 新增：`tools/lfs_mkfs.c`（littlefs 2.8.0 宿主端工具，create/verify/list）、
  `tools/make_firmware_bin.py`（拼装 + 四重校验）、
  `python_code/umqtt/simple.py` + `__init__.py`（自带 MQTT 依赖）
- 重写：`.github/workflows/build.yml` → 4 个 job
  （check / package(.mpy) / firmware(单文件 BIN) / publish）
- 修：`AMS_WEB.py` 首次启动 `config.json` 不存在时 `.update()` 抛 AttributeError
- README：一键烧录升为首选，补 CI/Release 说明、分区表、损坏死循环 FAQ
- `.gitignore`：排除 `dist/`、`tools/build/`

### 验证

- BIN 大小 **4194304 字节**，SHA256 `689dc708…93cc5`，两次构建**可复现**
- 四重校验：0xE9 魔数 / 分区表一致 / block0、1 的 offset8 有 "littlefs" 魔数 /
  用 littlefs-python 2.11 反向读取 2.8 生成的镜像
- `python tests/run_tests.py` → 18/18 通过
- 已本地提交 `00f53c8`，**未推送**（等用户确认；CI 一旦推送即自动发 Release）

### 待办 / 风险

- 之前仓库处于 `git pull --rebase` 冲突中（build.yml 有未合并标记），已
  `git rebase --abort` 复原，HEAD=47acaf9=origin/main，无数据丢失。
- 推送前请确认 CI 会拿到 `MICROPYTHON_FIRMWARE_URL` 的官方固件（外网可达）。
- 若日后升 MicroPython 版本，`MICROPYTHON_VERSION` / `LITTLEFS_VERSION` /
  `MPY_CROSS_VERSION` / 固件 URL / SHA256 五个变量必须同步改。

---

## YAO_AMS：网页极慢/打不开修复 + 联网策略 + Windows 风格取色器

用户反馈（实机刷固件后）：① 配网能连上但网页打开非常慢、偶尔打不开；
② 第一次配网成功后希望后续不再扫描 WiFi；③ 连不上时 3 次后自动开 AP；
④ 优化网页；⑤ 通道颜色弹窗做成 Windows「颜色」对话框那样。

### 根因定位（网页慢 / 偶尔打不开）

按影响从大到小：

1. **`hanld_rootv2` 逐行发 HTML + 每行 `await sleep_ms(10)`** —— index.html
   400 多行，光发送就 4 秒以上，且每行一个 TCP 小包，还不带 `Content-Length`。
2. **主循环用阻塞的 `wait_msg()`** 收 MQTT —— `umqtt.simple.wait_msg()` 里
   `sock.read(1)` 是阻塞读，没消息时把整个 uasyncio 事件循环按住，
   Web 与状态灯任务全部饿死。这是"偶尔打不开"的元凶。
   → 解法：`check_msg()`（它会把 socket 设非阻塞、read 返回 None；
     `wait_msg` 内部读完后会恢复 blocking=True，所以后续 publish 仍安全）。
3. **`run_web_loop` 里 `await sleep_ms(500)`** —— 每个请求平均多等 250ms。
4. **读请求头 = 阻塞 recv + `settimeout(3.0)`** —— 浏览器会开"预连接"
   套接字却不发数据，服务端卡满 3 秒。
5. **`gc.threshold(1024)`** —— 每分配 1KB 就 GC 一次。
6. **一次页面加载发 5 个请求**（ip/wifi/mqtt/access/hardware），单线程串行。
7. **`get_wifi_info` 每次都 `scan()`** —— 阻塞 ~2 秒。
8. **每 20 轮重连一次 MQTT** —— 每轮都阻塞，实际几秒断一次，非常不稳。
9. **`check_mqtt_connection()` 每次真的发 PINGREQ** —— 状态灯每秒调一次。

### 最终方案

- `network_model.py` 重写：上电**不扫描**，读 `wifi.dat` 直连；
  最多 `WIFI_BOOT_ATTEMPTS=3` 次失败返回 None → 上层开 AP。
  成功判定必须是「关联上 **且** IP ≠ 0.0.0.0」（DHCP 没完成时连 MQTT 必失败）。
  密码错误/找不到 AP 立即返回，不白等。`scan_networks(force)` 带 60 秒缓存。
- `AMS_WEB.py`：index.html 内存缓存 + 一次发完；accept 轮询 20ms；
  `_read_request()` 非阻塞+await 让步，上限 `HEADER_WAIT_MS=600`；
  新增 `/status` 聚合接口；GC 阈值 16KB；favicon 返回 204。
- `bambu_mqtt.py`：`check_mqtt_connection(force=False)` 5 秒节流；
  新增 `poll_msg()`（非阻塞）与 `wait_msg_timeout(ms)`（带超时的换料等待）。
- `AMS_MODEL.py`：`run_ams_loop` 用 `poll_msg()`，只有真收到消息才
  `update_print_info()`（否则会把旧消息反复解析）；重连改
  `RECONNECT_INTERVAL_MS=300000`；查询打印机间隔 `PUSH_INTERVAL_MS=1000`。
- `index.html` 全部重写：Windows 风格取色器 + 手机自适应 + 2 秒轮询。

### 取色器实现要点

- 基本颜色是**程序生成的 6×8**：前 7 列按 `c*360/7` 铺色相 × 6 档明度，
  第 8 列是白→黑灰阶。比手写 48 个色值更整齐。
- SV 区用 CSS 渐变而不是 canvas：
  `linear-gradient(to top, #000, rgba(0,0,0,0)), linear-gradient(to right, #fff, hsl(H,100%,50%))`
- 拖拽用 Pointer 事件 + `touch-action:none`，鼠标/触屏通用。
- 灰色没有色相 → `setFromHex(keepHue)` 保留原色相，体验更顺。
- 输入框回写前判断 `document.activeElement`，避免打字时被覆盖。
- 自定义颜色存 localStorage（16 格，unshift + 去重）。
- `parseColor()` 支持 `#rgb` / `#rrggbb` / `rgb()` / 颜色名（用临时 div 让浏览器算）。

### 验证手段

- 测试 **18 → 41 项**，新增联网重试/热点回退/扫描缓存、网页性能回归
  （源码级断言：`hanld_rootv2` 不得含 `asyncio.sleep`、`run_ams_loop`
  不得含 `wait_msg()` 等）、MQTT 节流行为。
- 装了 `agent-browser`（Chrome 153）做真实渲染验证：
  页面总览、取色器（红色 / 调到 HSV 200,80,90 → #2EA8E6）、
  390px 手机端无横向溢出。截图存 `dist/preview-shots/`（已 gitignore）。
- 新增 `tools/preview_server.py`：本地假数据服务，PC 上预览页面用。
- 固件重新构建通过：4MB，18 个文件，SHA256 `e48d1cb4…18f2d`
  （本地未装 littlefs-python，跳过了独立交叉校验，CI 上会做）。

### 待办 / 风险

- **本地推 GitHub 一直失败**（`schannel: server closed abruptly` /
  `Connection was reset`），多次重试无效。用户自己推是通的，
  需要用户手动 `git push` 或配代理。本地已提交 `578ed36`。
- 换料那十几秒网页仍会卡住，这是有意保留的（电机时序不能被协程打断）。

---

## 二、"接上负载后一直重启 / 电机一直叫 / 网页打不开"

用户报障：刷完固件配好 WiFi 能连网，但接上负载后电机一直有电流声
（一会长鸣、一会间隔响），板子像在反复重启，网页打不开。
硬件：H 桥 **AT8236**，离合驱动 **ULN2803**，用户想把电机 IO 设成 IO2(IN1)/IO3(IN2)。

### 根因（按确定性排序）

1. **GPIO2 / GPIO3 是 ESP32-C3 的 strapping 启动模式脚。**
   依据《ESP32-C3 技术参考手册》第 7 章表 7.2-1：复位释放后由
   **GPIO2、GPIO3、GPIO8、GPIO9** 共同控制 Boot 模式。
   ⚠️ 旧版 `hardware_config.py` 的 strapping 列表只有 2/8/9，**漏了 GPIO3**。
   datasheet 表 4-1 写得很清楚：GPIO2、GPIO8 复位后是**浮空**，
   四个脚里只有 GPIO9 带内部弱上拉。
   → **AT8236 的 IN1/IN2 是"逻辑输入，内置下拉电阻"**（数据手册管脚表原文），
   接上去就把 GPIO2/GPIO3 在上电瞬间拉低，芯片进不了正常启动模式 → 复位循环。

2. **GPIO2 上本来就挂着 1kHz 的状态灯 PWM**（`AMS_WEB.py` 的
   `PWM(Pin(LED_PIN))`，`status_lED()` 里 MQTT 通 → `duty(1000)` 常亮，
   只连 WiFi → 0.5s 亮/0.5s 灭）。IN1 也接 GPIO2 的话，
   电机就跟着状态灯闪 —— **"长鸣 / 间隔响"的规律和状态灯状态一一对应**，
   这是最能一眼确诊的一条。
   另外 `device_processing.huxideng()` 还有一处 `PWM(Pin(2))` 呼吸灯
   （已确认**没有被调用**，属死代码）。

3. 供电：AT8236 的 VM 是 5.5~36V 功率电源，若和 3.3V 共用细线，
   电机启动浪涌会把电源拉塌 → 欠压复位。这类"空载正常、一挂负载就重启"
   是欠压复位的典型特征。

4. AT8236 的限流：`I= VREF/(10*RISEN)`，VREF=2.0V / RISEN=0.2Ω 只有 1A，
   带载会"堵转式"嗡嗡响但不转 —— 也可能被误认为"没启动成功"。

### 改动

- **hardware_config.py**
  - `STRAPPING_PINS = (2, 3, 8, 9)`，补上 GPIO3
  - `SAFE_OUTPUT_PINS = (0, 1, 4, 5, 6, 7, 10)`
  - 电机接 strapping 脚 = **硬错误**；离合/LED 接 strapping 脚 = **警告**
    （ULN2803 输入是达林顿基极，要 1.4V 才导通，空闲时高阻≈悬空，
     而 GPIO2/3/8 官方默认就是浮空，所以能跑但属"带病运行"）
  - 新增 `output_pins()` / `input_pins()` / `validate_detail()` /
    `boot_safety_report()`；`validate()` 仍是 `(ok, problems)`，
    只有错误才让 ok=False（向后兼容）
  - `LED_PIN` 支持 `None`；新增 `MOTOR_BOOT_SETTLE_MS = 200`
  - 电机引脚**保持 GPIO4/GPIO5 不变**（用户想改的 2/3 是本次故障根因）

- **reset_info.py（新模块）**：`capture()` 读 `machine.reset_cause()` 并翻译成
  中文（BROWN_OUT_RESET / WDT_RESET / PWRON_RESET …）、`make_safe()` 上电把
  电机/离合/LED 置到不上电电平、`record_boot()` / `clear_boot_count()`
  写 `boot_stat.json` 记启动次数（数字疯涨 = 复位循环）。
  用 `dir(machine)` 里以 `_RESET` 结尾的名字反查，**不写死数字**。

- **boot.py**：`make_safe() → capture() → record_boot()`，整段包在
  `try/except Exception` 里，绝不挡住 main.py。

- **device_processing.py**：`BOOT_SAFETY` 全局字典（**用 `update()` 原地改，
  不能重新赋值**，否则 AMS_WEB import 到的是旧对象）；
  `build_motor_bus()` 先跑引脚自检打日志，再等 `MOTOR_BOOT_SETTLE_MS` 才挂 H 桥。
  引脚有错**仍然创建硬件**（否则网页都打不开，没法看诊断）。

- **AMS_WEB.py**：`/status` 增加 `reset` + `boot_safety`；新增 `GET /boot_clear`；
  `LED_PIN is None` 时跳过 PWM 且 `status_lED()` 直接 return。

- **index.html**：新增「上电诊断」卡片（复位原因 / 原因说明 / 启动次数 /
  已运行 / 引脚自检 + 重置启动计数按钮）。启动次数 > 5 标红"在反复重启"。

### 验证

- 测试 **41 → 54 项**，新增 13 项：strapping 含 GPIO3、电机接 2/3 必须报错、
  离合接 3 只警告、`make_safe()` 电平、`make_safe` 抗坏脚、boot.py 调用顺序、
  复位原因可序列化、启动计数累加清零、`/status` 含诊断字段、LED 可禁用。
- JS 语法 `node --check` 通过；`agent-browser` 实际渲染截图确认诊断卡片
  （BROWN_OUT_RESET 标红 + "37 次 · 在反复重启" + 引脚自检未通过两条红字）。
- 固件重编：4MB，**19 个文件**（多了 reset_info.py），
  SHA256 `4c6a0204…d55f`。

### 待办 / 风险

- **用户仍需改线**：电机 IN1/IN2 从 IO2/IO3 挪回 GPIO4/GPIO5。
  如果 GPIO4/5 不可用，备选是 GPIO0/GPIO1。
- 4 号离合仍在 GPIO3（strapping）上，建议改到 GPIO1，但没强制。
- 本地推 GitHub 仍需代理：`git -c http.proxy=http://127.0.0.1:10808 …`。
- 未做：AT8236 限流（VREF/ISEN）的实际测量，需要用户在硬件上确认。

---

## 18:35 后：AP 能连上但管理页打不开（memory allocation failed, allocating 36096 bytes）

**现象**：刷写固件后能连上 AMS_WIFI 热点，但 `http://192.168.4.1` 打不开；
串口每隔几十毫秒刷一行 `处理请求出错: memory allocation failed, allocating 36096 bytes`。

**根因（已确认）**：`AMS_WEB.hanld_rootv2()` 里 `open("index.html","r").read()`
把 **40KB 的整份页面读成一个字符串**（外加 `send_response` 里 `.encode()` 的第二份拷贝）。
ESP32-C3 空闲堆只有几十 KB 且碎片化，拿不到连续 36~42KB → MemoryError；
更要命的是 `_index_cache` 根本没写进去，于是**每个请求都在同一处再失败一次**，
页面永远打不开。全项目只有这一处大对象分配（grep `.read()` 只有它），
且此前 `gc.collect()` 一次都没调用过。

**修复**：
- `AMS_WEB.send_file()`（新）：`os.stat()[6]` 取长度写 `Content-Length`，
  正文 `open(path,"rb")` 每次只读 `FILE_CHUNK=1024` 字节 → `sendall`，
  块间 `await asyncio.sleep_ms(0)` 让步；发送前 `gc.collect()`。
  单次最大分配从 40KB 降到 1KB，且没有第二份拷贝。
- 删除 `_index_cache`（测试里加了 `hasattr` 断言防复活）。
- 新增 `_raw_send()` 统计本次连接已发字节 + `oom_respond()`：
  **仅当一个字都没发出去时**才补一个极小 503 页面（否则会把半个响应拼坏），
  浏览器不再纯白屏。
- 所有请求异常日志都带上 `mem_note()`（空闲内存 xxx 字节）；
  `/status` 增加 `mem_free`，网页「上电诊断」卡片新增「空闲内存」一行（<20KB 标红）。
- `AMS_MODEL.run_ams_loop`：WiFi 未连接（AP 模式）时不再每 10 秒空转建 MQTT，
  改为退避 30 秒 + 日志降频，串口不再被「未连接wifi」刷屏。

**验证**：
- 测试 54 → **58 项全通过**。关键新测试是**真实功能测试**：
  `_FakeSocket` 假 socket + 真机上那份 42KB 的 `index.html` 实跑
  `hanld_rootv2`，断言逐字节一致、`Content-Length` 正确、
  **单次发送不超过 FILE_CHUNK**（就是"不会再 OOM"的硬证据）。
- 踩坑记录：`inspect.getsource` 会把我自己写的「千万别用 f.read()」注释/
  文档字符串也算进去，误伤断言 → 加了 `_code_only()` 按行跳过 docstring 与注释行
  （不能用 `src.replace(fn.__doc__, "")`，编译器给的 `__doc__` 与源码文本
  在缩进/转义上不保证逐字相同）。
- 踩坑记录 2：**同一文件不要并行发两个 Edit**，会互相覆盖丢改动
  （这次 index.html 的 JS 与 `_code_only` 各丢了一次）。
- 页面 JS `node --check` 通过；无头浏览器渲染确认「空闲内存 18.0 KB · 偏低」标红。
- 固件重编：4MB / 19 文件，SHA256 `0f4409b4…d138c0f`。

### 待办 / 风险

- 本次提交**未推送**，等用户确认后走代理推（`http.proxy=http://127.0.0.1:10808`）。
- 若刷完最新固件仍报 OOM：看串口那行「空闲内存 xxx 字节」——
  低于 20KB 说明别处有泄漏，需要进一步查（此时 1KB 块也可能分配不到）。

---

## 2026-09-16 网页改版：左侧菜单 + 右侧内容与日志（commit 576e4f7）

用户贴了网页截图，一次提了 5 个问题，逐条处理。

### 1) 默认 4 通道 / 硬件调试一直"加载中"
`renderAccess` 原来只在 `applyStatus` 里调用，接口一慢或出错就永远停在占位符。
→ `boot()` 里先用 `DEFAULT_CHANNELS=[1,2,3,4]` + `DEFAULT_COLORS` 调
`renderAccess` / `ensureHwButtons` / `updateHardware`，接口回来再覆盖。
同时 `/status` 瘦身：**去掉 `boot_safety.report`**（一大段中文，是 OOM 主因）、
每个字段用 `_safe()` 兜底、`ssids` 限 12 个；中文响应改 512 字节分块 encode
（`_str_chunks`），避免 `.encode()` 一次性再复制一整份。

### 2) 联网后不再显示 WiFi 配置
菜单项标 `apOnly`，`applyWifiVisibility()` 按 `apOn`（来自 `/status` 的
`ap_on`）加/去 `.item.hide` 类；CSS 用 `.item.hide{display:none}` 而不是内联
display —— 内联 display 会被 `showPage` 的 classList 操作绕过。热点关掉时
若正好停在 WiFi 页则自动跳回运行状态。配网成功后立即 `swcith_ap(0)`（先回包再关）。

### 3) MQTT 保存 404 + 不持久化
根因：POST 请求体经常落在**下一个 TCP 段**里，`_read_request` 读完请求头就返回，
`process_json` 拿到 None → 落进 404 分支，真机上一保存就 404。
→ 按 `Content-Length` 把请求体读齐（非阻塞 + `await asyncio.sleep_ms(10)` 让步，
`BODY_WAIT_MS=800` 上限）；`WRITE_ROUTES` 收到 `data is None` 明确回 **400**
（`handle_bad_body`），不再用 404 误导。
另外 `handle_mqtt_cennect` 改成**先 `updata_data` 落盘、再
`conent_and_subscribe`**，所以 AP 模式（连不上打印机）下也能保存成功；
返回 `{info, saved, connected}`，网页能区分"已保存但没连上"和"彻底失败"。

### 4) 每个目录默认折叠
展开状态存 localStorage（`ams_menu_open`），默认空 = 全折叠。
**踩坑**：`showPage()` 原来会"顺手"展开当前页所在目录，而 `boot()` 必然调一次
`showPage()`，于是侧栏一进来就有 1 个目录是摊开的 —— 跟"默认折叠"直接矛盾。
→ `showPage(id, autoReveal)` 加参数，展开只发生在用户点菜单
（`showPage(it.id, true)`）这一条路径；开机/刷新一律不展开。新增
`test_page_directories_stay_folded_on_boot` 钉住。

### 5) 左右分栏
`.app{display:grid;grid-template-columns:216px minmax(0,1fr)}`：左
`<aside class="side">` 菜单，右 `<main>` 内容 + 右下角常驻
`<section class="logbox" id="logbox">`。日志面板每 2s 拉 `GET /log`
（`d.log` + `d.mem_free`），含 `★`/`失败`/`出错` 的行标红，自动滚到底。
`≤820px` 侧栏变 ☰ 抽屉（`.side` `translateX(-100%)` + `.side.open` + `.scrim` 遮罩）。

### 其他
- 新增 `GET /log`、`POST /ap_set`；`tools/preview_server.py` 同步支持，
  第二个参数传 `ap` 即可模拟热点模式（`python tools/preview_server.py 9001 ap`）。
- `logout.py` 加环形缓冲：`LOG_MAX_LINES=24`、`LOG_LINE_MAX=100`，
  `recent(count=None)` 返回副本 + `clear()`。参数顺序故意保持
  `(info, is_print, is_save, is_error)`，兼容上游 `logout("发布出错了", e)`。
- `info_load.py`：`write_json_file` 去掉笔误的逗号；`read_json_file` 改捕获
  `Exception`（不只 `OSError`），config.json 损坏也能起来；默认值改
  `client_id=mqttx_3c73cd31`、`mqtt_port=8883`，键名 `password` → `mqtt_password`。
- `bambu_mqtt.auto_conent_MQTT` 全改 `.get()` 兜底并兼容新旧键名，不再 KeyError。

### 验证
- 测试 **78 项全通过**（新增约 19 项：`/status` 体积与容错、请求体分段到达、
  空体回 400、先落盘再连接、默认折叠、`/log` 环形缓冲、中文 Content-Length 等）。
- 无头 Chrome（agent-browser）实测：
  - 桌面：3 目录全折叠、WiFi 项隐藏、4 通道 + 8 个点动按钮、日志 15 行、无横向溢出。
  - **手机 390×780**：`scrollWidth==clientWidth`（无溢出）、`.side` `left=-238`
    （完全移出屏）、`#menu_btn` `display:block`、3 目录 **0 个 open**、
    `gitems` 渲染 0 个、WiFi 项 `display:none`、日志面板 168px、8 个点动按钮。
  - 点 ☰ → `side.open` 且 `left=0`、scrim `block`；点目录标题 → 该目录 open、子项显示。
  - AP 模式（9001）：badge 变「热点模式」、WiFi 项 `display:block` 出现。
- 固件重编：4MB / 19 文件，SHA256 `84bfb806…869cf187`；
  grep 确认新页面文本（`autoReveal`）确实进了 BIN。

### 踩坑 / 环境（下次省时间）
- 本机 bash（WorkBuddy shell shim）里 `dirname`/`head`/`tail`/`cat` 全缺失，
  先 `export PATH="/c/Program Files/Git/usr/bin:$PATH"` 才恢复。
- `agent-browser` 不在 PATH，实际路径：
  `C:\Users\lkfcs\.workbuddy\binaries\node\workspace\node_modules\agent-browser\bin\agent-browser-win32-x64.exe`。
- **改视口必须写 `agent-browser set viewport 390 780`**（少个 `set` → "Unknown command"）。
  **`eval` 的 JS 必须单行**，多行会被 PowerShell 参数传递切碎，报
  `SyntaxError: Unexpected token '.'`；用 bash 单引号包住最稳（里面别出现单引号）。
- `make_firmware_bin.py` 的 `SKIP_SUFFIXES` 含 `.mpy` —— **固件直接打包
  `python_code/` 下的 .py 与 index.html 源码**，不需要 mpy-cross；
  `build_mpy.py` 只是另一条部署路径，本机没装 mpy-cross 不影响出固件。
- 截图目录要先存在，否则 agent-browser 报 `os error 3`。

### 待办 / 风险
- 本次提交（576e4f7）**未推送**，等用户确认后走代理推
  （`http.proxy=http://127.0.0.1:10808`），CI 会重编 `latest`。
- 本地 `dist/index.html`（18956 字节）是旧残留，与真机用的
  `python_code/index.html`（57895 字节）不同步；只是中间产物，不影响 BIN。

---

## 22:2x 用户 5 条抱怨收口：卡死/点动转圈/进退响应时间/MQTT 假失败/OTA

用户原话 5 条：①系统太慢、刷新打不开、要刷好几次才出页面 ②网页调试按通道一直
转圈、几十秒后才有动作 ③硬件调试加"进退响应时间"、4 个通道统一 ④系统里加 OTA
菜单能上传 BIN 在线更新 ⑤MQTT 设置提示失败、重启几次又自动连上。

先问清了两件事：OTA 选**应用层**（分区表只有单个 factory，没有 ota_0/ota_1，
整机 BIN 做不了真 OTA）；进退响应时间**只管手动点动**，不动自动换料时序。

### 改了什么（commit 2c9eb34，11 文件 +3094/-221）

- **/status 彻底去掉网络 I/O**：新增 `mqtt_alive_cached()` 只读缓存标志。
  页面每 2 秒轮询它，以前每次都触发 TLS ping —— 这是"页面假死"的根因。
- **HTTP 改 worker pool**（`WEB_WORKERS=3`）+ `LISTEN_BACKLOG=8`。
  浏览器会并发开好几条连接，原来 backlog=2，后面的直接被 RST，
  表现就是"第一次打不开、刷几次才出来"。
- **首字节窗口 600ms → 180ms**：浏览器会开"预连接"套接字却一个字都不发。
- **MQTT 探测加 0.8s 硬超时 + `tcp_reachable()` 预探**；打印机没开机时先探 TCP，
  通不过就跳过，不再让 SSL 卡到系统超时（"周期性整体假死"的来源）。
- **`close_client()` 修 socket 泄漏**：旧连接真正关掉。
- **电机总线改两段式非阻塞**：`begin()` 立刻返回，`finish()` 在
  `await asyncio.sleep_ms` 后收尾。原来走同步 `bus.run()`，里面
  `time.sleep_ms` 按住整个事件循环，Web 和 LED 一起停摆 —— 这就是"点一下转圈几十秒"。
- **/hardware_test 改"立刻回包 + 后台计时"**；总线忙时立刻拒绝，**绝不排队**。
- **新增 POST /jog_set**：收 `{"seconds":3}` 或 `{"ms":3000}`，落盘 config.json，
  clamp 到 [200ms, 60000ms]，被夹会如实说明；`/status` 暴露 `jog_ms`，
  按钮上的秒数跟着设备值走，不写死。
- **MQTT 保存语义改"先落盘再后台连"**：写进 config.json 就回 `saved=true`，
  不再拿"连没连上"当保存结果；区分 `connecting/connected`；
  必填项留空回 400 并点名；用户名/客户端名/端口留空用默认值补齐。
- **应用层 OTA**（`ota_update.py` + `tools/make_update_pack.py`）：
  `.ams` 包（magic `AMSUPD1\n` + 清单 + 逐文件 CRC32），流式接收 → 写 `*.new`
  → 全量校验通过才原子改名 → 重启。拒绝越权路径、拒绝覆盖
  `config.json/wifi.dat/boot_stat.json`、误传整机 BIN 时提示改走 USB。
  新增 `dist/esp32c3-ams-update.ams`（308365 字节 / 20 文件）。
- **修掉一个会让真机全站 500 的 bug**：路由正则 pattern 是 `str`、请求头是
  `bytes`，MicroPython 的 `re` 要求两者同类型 → `TypeError`。统一改 bytes 模式，
  并补了回归测试 `test_web_routing_works_on_raw_bytes_headers`。
- 自测 **78 → 116 项全过**；README 更新功能表/接口表/性能表（按用户原话逐条对应）
  /OTA 专章/FAQ。

### 又发现并修掉：预览服务 OTA 上传死锁（commit 34d517b）

验证 OTA 页面时，上传永远停在"正在上传…"，几十秒后超时。真机固件没问题，
是 `tools/preview_server.py`：

- **`do_POST` 一进来就无条件 `self._body()` 把请求体读掉当 JSON 解**，
  轮到 `/ota_upload` 再调 `self._raw_body()` 时已无数据可读 →
  永远卡在 `rfile.read(length)` 等一个永不到来的 308KB。socket 是单向流，
  **请求体每个请求只能读一次**。改成 `_read_body()` 读一次 + `_parse_json(raw)`。
- **`HTTPServer` → `ThreadingHTTPServer`**：一边收几百 KB 包、一边要响应
  页面每 2 秒的 /status 与 /log；单线程时轮询被上传挡住，浏览器等不到响应
  就把上传连接一起掐掉（服务端看到 `ConnectionResetError`）。
- README 补：预览里 OTA 是"只演练、不落盘"（解到临时目录校验完就删，
  不覆盖 `python_code/`），以及为什么必须多线程。

### 验证（这次是真机之外的"真渲染 + 真接口"）

- **curl 打真实接口**：垃圾体 → 400「更新包不完整（只收到 5 字节）」；
  真实 `.ams` → 200 `{"ok":true,"files":20}`；整机 BIN（4MB）→ 400 + USB 提示；
  `python_code/` 下无 `.new` 残留。
- **agent-browser 实跑**（截图存 `dist/preview-shots/`）：
  - 1400×950：7 个菜单项、无横向溢出；390×780：`scrollWidth==clientWidth==390`、
    侧栏 `left=-238` 完全移出屏、☰ `display:block`。
  - **进退响应时间端到端**：初始"1 秒"→ 填 2.5 → 保存 → 4 个通道按钮全变
    "进料 2.5 秒"、状态行变"2.5 秒（4 个通道统一）"、
    日志出现"进退响应时间已改为 2.5 秒（4 个通道统一生效）"。
  - **点动即时反馈**：按下 900ms 内页面已显示"总线状态 正在动作（通道1）"、
    离合1 吸合、电机方向 1；2.5 秒后日志出现"点动结束，电机已停、离合已全部断开"。
  - **OTA**：传 `.ams` → "升级已写入。设备正在重启，请等约 15 秒后刷新页面…"；
    传整机 BIN → 页面直接给 USB 提示，日志 `★ 升级包被拒绝` 标红。
- 固件 BIN **无法在本机重编**（无 gcc / 无 littlefs 源码，`lfs_mkfs` 二进制不在），
  归 CI；`.ams` 包是已验证的"不插 USB"投递路径。

### 踩坑（下次省时间）

- **agent-browser 没在 PATH**，实际入口：
  `C:\Users\lkfcs\.workbuddy\binaries\node\workspace\node_modules\agent-browser\bin\agent-browser.js`
  —— **用 `node <该 js>` 跑，别直接跑那个 .exe**（exe 会被环境干掉 / 无输出）。
- **多步操作必须用 `batch`，一次调用把命令全做完**。单独跑 `open` 会让整个
  PowerShell 脚本在第 1 行后中断（exit 1），后续命令全不执行。
  `batch` 从 **stdin** 读**一个** JSON 数组的数组（不是 JSONL！），
  用 `Get-Content -Raw -Encoding UTF8` 喂进去。
- **中文进 native 进程的 stdin 会被 ASCII 化**：PowerShell 5.1 里必须设
  `$OutputEncoding = New-Object System.Text.UTF8Encoding($false)`
  （光设 `[Console]::OutputEncoding` 只能让 *输出* 不乱码，不够）。
  否则 eval 里的中文选择器匹配不到 → 报 "Cannot read properties of undefined"。
- **Windows 上 SO_REUSEADDR 允许两个进程同时绑同一端口**：上次会话残留的
  `dist/_preview/server.py` 一直占着 8099，新起的服务收不到连接，
  害我以为是新代码有问题。排查端口先 `Get-CimInstance Win32_Process`
  看**命令行**，别只看 `Get-NetTCPConnection`（它会漏掉一条）。
- `Get-ChildItem ... | Remove-Item` 在这个环境里删不掉文件，`/usr/bin/rm` 可以。

### 待办 / 风险

- 两个提交（2c9eb34 / 34d517b）**都未推送**，等用户确认后走代理
  （`http.proxy=http://127.0.0.1:10808`）。
- 固件 BIN 需 CI 重编才带上本次新代码；设备侧可先用 `.ams` 包升级。
- 预览服务已用修复后的代码跑在 8099（后台任务 BuCchq），
  `Get-Content` 的 stdout 是块缓冲的，所以看不到启动横幅是正常的。

---

## 刷机后热点起不来 / Web 起不来：四层坑全修完（commit 51ec834）

用户贴串口日志：`RuntimeError: Wifi Unknown Error 0x0101`（板子崩在
`network_model.__init__` 建 WLAN 对象那步），要求上机确认根因并推板验证。

**总根因**：ESP32-C3 上 MicroPython 的 GC **不做压缩**。应用一加载完，
空闲还有 64KB，但**最大连续块只剩 3,584 字节**（`gc.collect()` 只多合出 2KB）。
之后任何"要一大块连续内存"的操作都会失败，失败方式还不一样：
有的抛 `0x0101`（= ESP_ERR_NO_MEM，MicroPython 的 WiFi 错误表只映射
0x3001~0x300E，其它一律显示 "Wifi Unknown Error"），
有的**直接硬复位**——没有 traceback、没有 Guru Meditation，只有 HARD_RESET。

**四层，逐层实测数据（板子串口实测，非推测）**

| 层 | 现象 | 实测 |
| --- | --- | --- |
| 1 | 建 WLAN 对象就 0x0101 | 干净堆 196,992 → 建两对象 172,352（AP 那份 24,576） |
| 2 | 开热点时每 3.3s 硬复位 | 干净堆开 AP 只花 4,176~4,592 字节；加载完应用再开 → 硬复位 |
| 3 | 热点已开，config() 仍 0x0101 | `ap.active()`=True、`ifconfig()` 正常，但 `config(essid/password/authmode)` **任一参数**都 0x0101；`active(True)` 再来一次是 no-op |
| 4 | 扫描/连接 WiFi 会硬复位 | `scan_networks()`/`do_connect()` 里有 `wlan_sta.active(True)`，而 STA 从未在干净堆上开过 |

**修法（一句话）：凡是"要占一大块、且只在启动时做一次"的资源，全部抢在应用加载之前申请。**

- `main.py` 第 0 步：建 AP/STA 两个 WLAN 对象 **并** `sta.active(True)` 真开射频
  （AP 已起时 STA 只花 **48 字节**，驱动共用；零成本换掉运行期所有 `active(True)` 变 no-op）
- 第 0.5 步：`auto_connection()` 失败才 `swcith_ap(1)` 开热点
- 第 0.6 步（新）：`boot_resources.prepare_web_server()` 趁干净堆建好 `:80` 监听 socket
- `network_model.__init__` **不许再 `active(False)`**（继承链会重跑，把刚开好的口关掉）
- `swcith_ap(1)` 改**幂等**：热点已 active 直接返回，绝不再 `config()`
- `AMS_WEB.run_web_loop()` 复用预建 socket，`boot_resources.take_web_server()`

**板子实测结果**：60 秒冷启动观察——只启动一次（第 919 次），
`reset_banner=0 / traceback=0 / oserror=0 / memoryerror=0`；
热点 1.54s 起来，Web 服务 4.26s 起来（`Web 服务已启动，监听 0.0.0.0:80（3 个 worker）`）
然后安静待机。桌面自测 **116/116 通过**。

**已本地提交 `51ec834`，未推送**（用户明确要求先不推）。

### 串口推送 / 探测工具链（这次重新搭的，下次直接复用）

- 本机没有 pyserial，全部走 .NET `System.IO.Ports.SerialPort`（COM22，CH343）。
  **`DtrEnable=$false` 必须保持**，否则拉一下就进下载模式；复位用 RTS 脉冲。
- **PowerShell 直接 stdout 不可靠**，一律重定向到临时文件再读回。
- **`.ps1` 必须纯 ASCII**：WinPS 5.1 把无 BOM 的 UTF-8 脚本按 GBK 解码，
  中文字符串字面量会乱码 → `-match '中文'` 恒为 0（踩过，误以为全是 0）。
  另外注释行以多字节字符结尾时换行会被吃掉，吞掉下一行。
- 推文件用 **base64 分块追加**：`open(f,'wb')` 写第 0 块，之后 `'ab'`。
  **每个分块要逐行 `f.write(ubinascii.a2b_base64("84字符"))`**，
  不要拼成一个 16KB 大字符串再解（实测 `MemoryError: allocating 44032 bytes`）。
- 每文件写完**必须 SHA256 读回比对**，全部 OK 才复位；失败绝不复位（避免半截文件）。
  校验读文件用 2KB 分片 update，别 `read()` 整份。
- 脚本在 `C:\Users\lkfcs\AppData\Local\Temp\`：`push4.ps1`（推+校验+看启动）、
  `bootwatch.ps1`（纯看启动 N 秒）、`probe_*.ps1`（各类单项探测）。

### 探测时踩到的坑（别再踩）

- **`settimeout()` 之后 `connect()` 会报 OSError -203**；不设就正常。
- **自发自收（loopback）测 HTTP 不可靠**：`accept()` 之后 `cli.send()` 会卡死，
  换 `_thread` 跑 main_task 又 `can't create thread`。别再往这条路上花时间，
  真要验网页就**用手机/PC 连 AMS_WIFI 开 http://192.168.4.1**。
- 探测脚本里手动 `gc.collect()` 前别用二分法测最大连续块 —— 分配再释放本身
  就会把堆切碎，导致后面 import 直接 MemoryError（自证预言）。

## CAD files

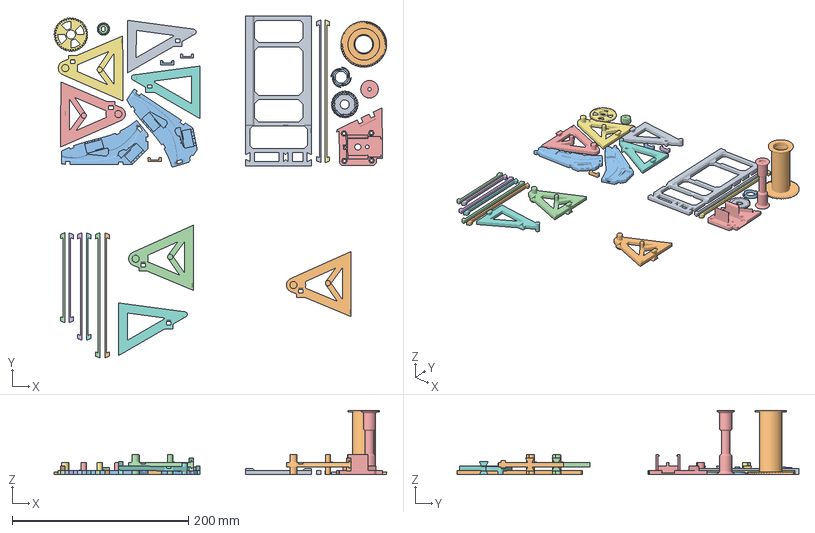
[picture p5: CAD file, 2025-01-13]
打印件/YBA-ams打印件/ALL.3mf
377.0 x 387.7 x 73.0 mm
底座
加强筋 中 x2 x 2
缓冲器 短 x2 镜像 x 2
侧边 主动(单边) x 2
加强筋 短 x2 x 2
加强筋 1 x 2
侧边 主动(双边) x 2
加强筋 超短 x2 x 2
电机固定座
棘轮 外
侧边 被动(双边)
棘轮 内
滚轮 主动
棘轮 中
电机轴齿
滚轮 被动
缓冲器卡扣 x 3
侧边 被动(单边 右侧) x 2

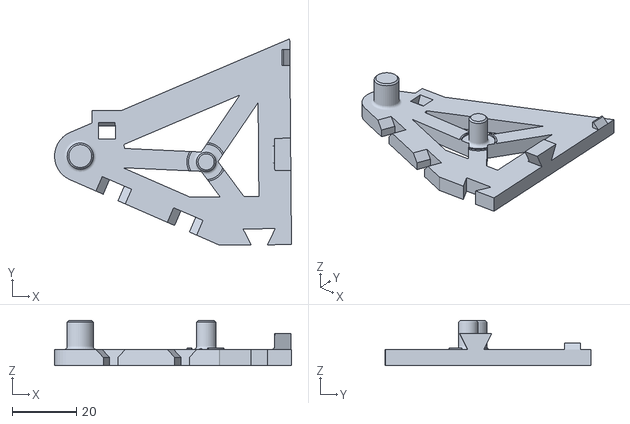
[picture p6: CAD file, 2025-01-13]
打印件/底座/支撑架L12.stl
73.6 x 64.1 x 14.0

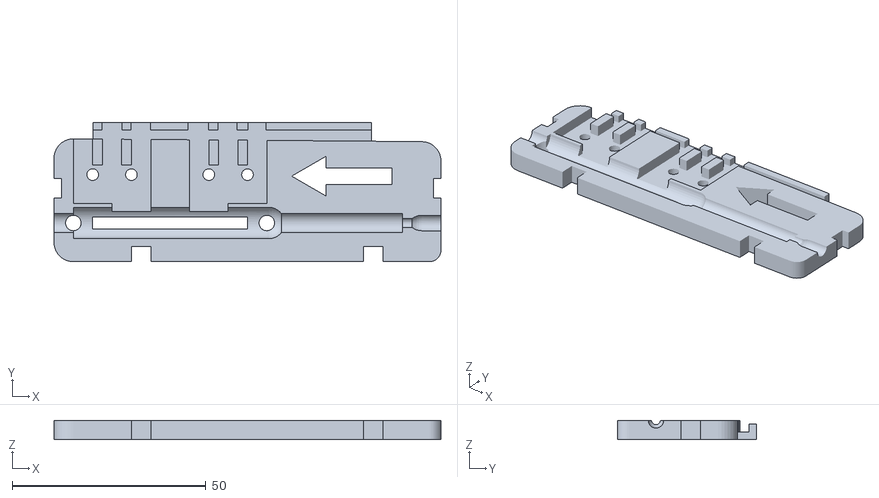
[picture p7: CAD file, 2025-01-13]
打印件/改进版缓冲器/缓冲区左.STL
100.0 x 36.0 x 5.00

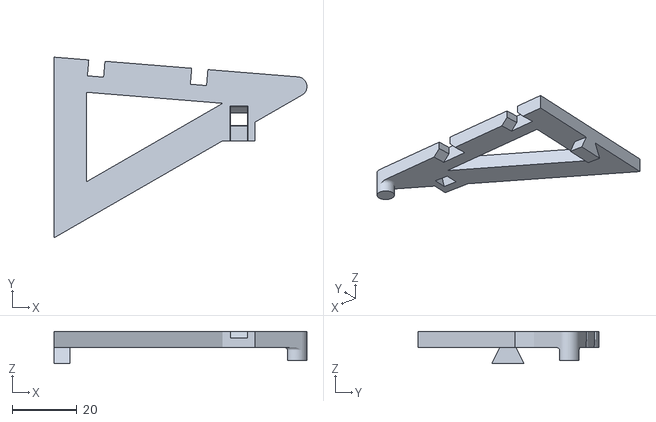
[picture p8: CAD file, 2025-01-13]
打印件/底座/支撑架L11.stl
78.1 x 55.8 x 10.0

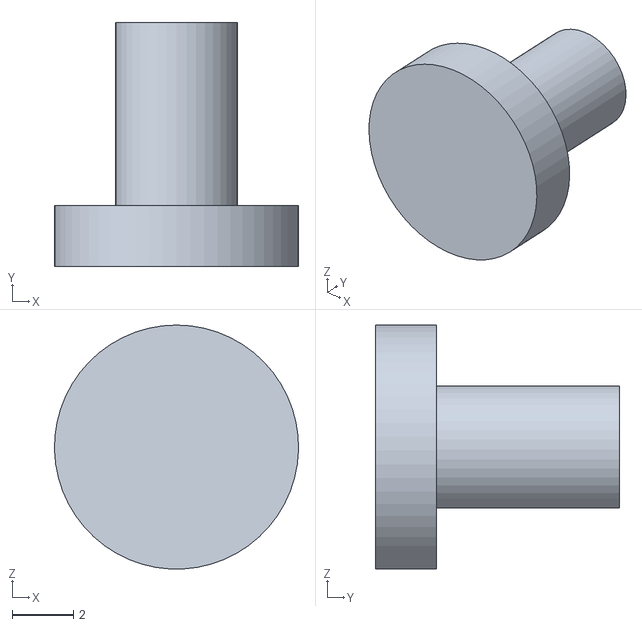
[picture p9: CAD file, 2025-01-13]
打印件/改进版缓冲器/固定器.STL
8.00 x 8.00 x 7.99

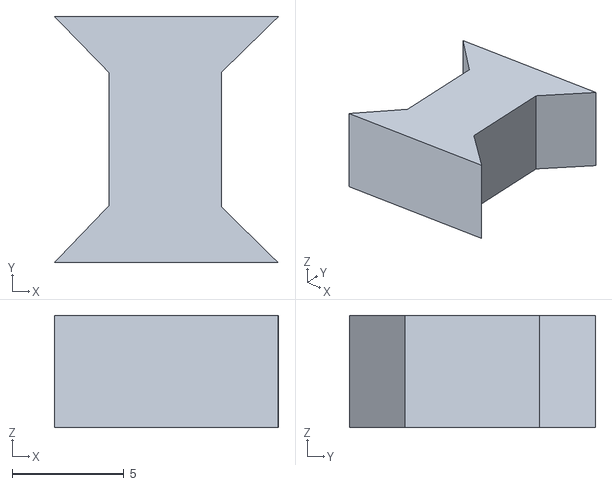
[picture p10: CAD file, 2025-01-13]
打印件/底座/连接器.stl
10.0 x 11.0 x 5.02

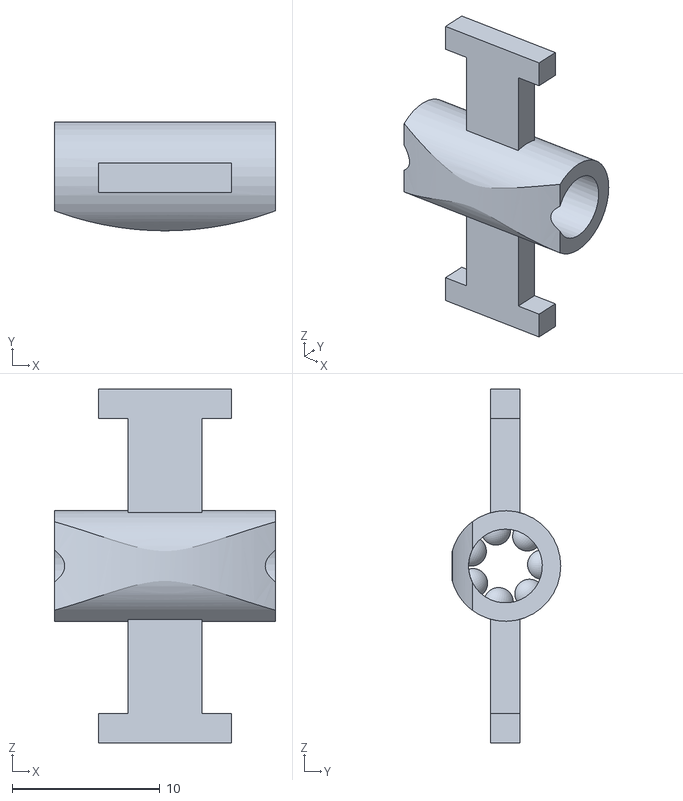
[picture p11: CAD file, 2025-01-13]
打印件/改进版缓冲器/中间件.STL
15.0 x 7.36 x 24.0

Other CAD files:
打印件/改进版缓冲器/缓冲区右.STL
打印件/底座/支撑架F12.stl
打印件/底座/支撑架F11.stl

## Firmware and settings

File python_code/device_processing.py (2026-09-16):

"""
device_processing.py —— 外设驱动与料盘位对象
=============================================

本文件包含两块内容：

  1. 通用外设小工具：呼吸灯(huxideng)、舵机(shiji)、28BYJ48 步进电机
     —— 保留原样，供扩展接口时使用。

  2. material —— **单个料盘位（通道）的门面对象**。

--------------------------------------------------------------------------
关于 material 的改造说明（重要）
--------------------------------------------------------------------------
老版本：每个料盘位各配 1 个直流电机，用 2 个 GPIO 组成 H 桥直驱。
        4 个料盘位就要 8 个 GPIO，而且用到 GPIO22/23 —— ESP32-C3 上根本没有这两个脚。

新版本：整机只有 **1 个共享直流电机 + 4 路电磁离合**。
        电机占 2 个 GPIO（H 桥 IN1/IN2），每路离合占 1 个 GPIO，合计 6 个 GPIO。
        要哪个料盘位送料，就吸合那一路的电磁离合，让它的送料轮咬上电机主轴。

因此 material 不再自己持有电机，而是变成"通道代理"：
        material.dianji_roll(方向, 时长)
            ↓ 内部展开为
        FilamentMotorBus.run(本通道, 方向, 时长)
            ↓ 即
        断开其它全部离合 → 吸合本通道离合 → 电机转 → 停 → 断开全部离合

为了不破坏 AMS_MODEL.py 里的换料逻辑，**旧接口名全部保留**：
        dianji_roll() / stop_roll() / dianji_top / dianji_bottom

其中 dianji_top / dianji_bottom 在老代码里是电机方向引脚，但 AMS_MODEL
一直把它们当**到位开关**在读（now_filament / fileament_move 里都是
`if dianji_top.value():`），所以这里直接改成到位开关对象，语义反而变正确了。
没有装开关时它们是 NullPin，.value() 恒返回"未触发"电平，不会报错。
"""

from machine import Pin, PWM
import time
import uasyncio as asyncio

from logout import logout
from hardware_config import (
    LIMIT_SWITCH_PINS,
    LIMIT_SWITCH_ACTIVE_LEVEL,
    LIMIT_SWITCH_PULL_UP,
    FILAMENT_STEP_MS,
    MOTOR_PIN_IN1,
    MOTOR_PIN_IN2,
    MOTOR_DEAD_TIME_MS,
    MOTOR_BOOT_SETTLE_MS,
    CLUTCH_PINS,
    CLUTCH_ACTIVE_LEVEL,
    CLUTCH_ENGAGE_MS,
    CLUTCH_RELEASE_MS,
    CLUTCH_SETTLE_MS,
    boot_safety_report,
)
from motor_clutch import (
    HBridgeMotor,
    FilamentMotorBus,
    LimitSwitch,
    NullPin,
    MotorBusError,
    ClutchConflictError,
    MotorBusyError,
    ChannelOutOfRange,
)


# ==========================================================================
# 一、通用外设小工具（保留原样）
# ==========================================================================


def huxideng():
    """GPIO2 呼吸灯效果（阻塞式，仅用于调试）"""
    pin2 = PWM(Pin(2))
    pin2.freq(1000)
    while True:
        for n in range(1000):
            pin2.duty(n)
            time.sleep_ms(1)
        for n in range(1000, -1, -1):
            pin2.duty(n)
            time.sleep_ms(1)


def shiji(pin, jiaodu):
    """舵机角度控制，jiaodu 为 -90 ~ 90"""
    p2 = PWM(Pin(pin))
    p2.freq(50)
    f = int(((jiaodu + 10) / 90 + 0.5) * 1023 / 20)
    p2.duty(f)


class stepping_motor_28BYJ48:
    """28BYJ48 四相步进电机（保留原样，供扩展接口使用）"""

    def __init__(self, pin1, pin2, pin3, pin4, delay_time_ms=2):
        self.pin1 = Pin(pin1, Pin.OUT)
        self.pin2 = Pin(pin2, Pin.OUT)
        self.pin3 = Pin(pin3, Pin.OUT)
        self.pin4 = Pin(pin4, Pin.OUT)
        self.delay_time_ms = delay_time_ms
        self.init_value()

    def init_value(self):
        self.pin1.value(0)
        self.pin2.value(0)
        self.pin3.value(0)
        self.pin4.value(0)

    def roll(self, rotation_number, direction=1):
        for n in range(rotation_number * 2050):
            value_list = [0, 0, 0, 0]
            value_list[n % 4] = 1
            if direction == 1:
                self.pin1.value(value_list[0])
                self.pin2.value(value_list[1])
                self.pin3.value(value_list[2])
                self.pin4.value(value_list[3])
            elif direction == -1:
                self.pin4.value(value_list[0])
                self.pin3.value(value_list[1])
                self.pin2.value(value_list[2])
                self.pin1.value(value_list[3])
            time.sleep_ms(self.delay_time_ms)
        self.init_value()


# ==========================================================================
# 二、硬件构建工厂
# ==========================================================================

# 上电引脚自检的结果，供网页显示（build_motor_bus() 里填充）
BOOT_SAFETY = {
    "ok": True,
    "report": "",
    "problems": [],
}


def build_motor_bus():
    """按 hardware_config.py 的配置创建"共享电机 + 4 路电磁离合"总线。

    ⚠️ 上电时会确保所有离合都处于断开状态，绝不会出现两路同时吸合。

    另外这里还会做两件和"接上负载就重启"直接相关的事：
        1. 先跑一遍引脚安全自检（strapping 脚不能当输出用），结果打到串口
           并且存进 BOOT_SAFETY，网页上也能看到；
        2. 等 MOTOR_BOOT_SETTLE_MS 毫秒再挂 H 桥 —— 上电瞬间电机/离合的
           浪涌最容易把 3.3V 拉塌，而 ESP32-C3 一旦欠压就复位。
    """
    ok, report = boot_safety_report()
    # 用 update 原地修改，不要重新赋值 —— 网页那边 import 的是同一个字典对象
    BOOT_SAFETY.update({
        "ok": ok,
        "report": report,
        "problems": [] if ok else [
            line.strip() for line in report.split("\n") if line.strip().startswith("×")
        ],
    })
    logout(report)
    if not ok:
        logout("!! 引脚配置有问题，硬件仍会被创建（好让你能打开网页看诊断），"
               "但请立刻按上面的提示改接线！")

    # 等电源稳定：欠压复位最常见的触发点就是"上电后立刻驱动负载"
    if MOTOR_BOOT_SETTLE_MS and MOTOR_BOOT_SETTLE_MS > 0:
        time.sleep_ms(MOTOR_BOOT_SETTLE_MS)

    motor = HBridgeMotor(MOTOR_PIN_IN1, MOTOR_PIN_IN2,
                         dead_time_ms=MOTOR_DEAD_TIME_MS,
                         name="filament_motor")
    bus = FilamentMotorBus(
        motor,
        CLUTCH_PINS,
        active_level=CLUTCH_ACTIVE_LEVEL,
        engage_ms=CLUTCH_ENGAGE_MS,
        release_ms=CLUTCH_RELEASE_MS,
        settle_ms=CLUTCH_SETTLE_MS,
        name="filament_bus",
    )
    logout("共享电机已初始化: IN1=GPIO%d IN2=GPIO%d，%d 路电磁离合 %s"
           % (MOTOR_PIN_IN1, MOTOR_PIN_IN2, bus.channel_count(), list(CLUTCH_PINS)))
    return bus


def build_materials(bus, limit_switch_pins=None):
    """按总线通道数创建料盘位对象列表。

    返回的列表下标 0 对应"料盘位 1"（物理位置），与电磁离合一一对应。
    注意：物理料盘位 ≠ 打印机的通道号，两者的映射由 access_list 决定。
    """
    pins = list(limit_switch_pins if limit_switch_pins is not None else LIMIT_SWITCH_PINS)
    channels = list(bus.channels)
    # 配置长度不足时补齐 None（未安装）
    while len(pins) < len(channels):
        pins.append(None)

    materials = []
    for index, channel in enumerate(channels):
        materials.append(material(channel, bus, limit_top=pins[index]))
    return materials


# ==========================================================================
# 三、料盘位（通道）对象
# ==========================================================================


class _HoldGuard:
    """material.hold() 的上下文管理器。

    进入：吸合本通道离合（自动断开其它所有通道）
    退出：停电机 + 断开全部离合（无论是否异常）
    """

    __slots__ = ("_material",)

    def __init__(self, mat):
        self._material = mat

    def __enter__(self):
        self._material.clutch_on()
        self._material._holding = True
        return self._material

    def __exit__(self, exc_type, exc_val, exc_tb):
        self._material._holding = False
        self._material.bus.release_all()
        return False


class material:
    """单个料盘位（通道）的门面对象。

    参数
    ----
    channel       : 本料盘位对应的电磁离合通道号（1 起）
    bus           : FilamentMotorBus 实例
    limit_top     : 退料到位开关的 GPIO（未安装传 None 或省略）
    limit_bottom  : 进料到位开关的 GPIO（未安装传 None 或省略）
    step_ms       : 单步推送时长，默认取 hardware_config.FILAMENT_STEP_MS

    推荐用法::

        mat.feed(1500)                     # 进料 1.5 秒
        mat.retract(1500)                  # 退料 1.5 秒
        with mat.hold():                   # 长时间连续动作
            for _ in range(10):
                bus.motor.run(1, 500)
                if mat.limit_triggered(1):
                    break

    兼容用法（老代码）::

        mat.dianji_roll(-1, 500)           # 退料 0.5 秒
        mat.dianji_top.value()             # 读到断开关电平
    """

    def __init__(self, channel, bus, limit_top=None, limit_bottom=None, step_ms=None):
        self.channel = channel
        self.bus = bus
        self.step_ms = step_ms if step_ms else FILAMENT_STEP_MS
        self._holding = False

        self.limit_top = LimitSwitch(limit_top,
                                     active_level=LIMIT_SWITCH_ACTIVE_LEVEL,
                                     pull_up=LIMIT_SWITCH_PULL_UP,
                                     name="ch%d-top" % channel)
        self.limit_bottom = LimitSwitch(limit_bottom,
                                        active_level=LIMIT_SWITCH_ACTIVE_LEVEL,
                                        pull_up=LIMIT_SWITCH_PULL_UP,
                                        name="ch%d-bottom" % channel)

        # ---- 兼容老代码的属性名 ----
        # 老代码把这两个当"到位开关"读，这里正好语义一致；
        # 未安装开关时是 NullPin，.value() 不会抛异常。
        self.dianji_top = self.limit_top.pin
        self.dianji_bottom = self.limit_bottom.pin

    # ------------------------------------------------------------------
    # 电磁离合
    # ------------------------------------------------------------------
    def clutch_on(self):
        """吸合本通道的电磁离合（会自动断开其它所有通道）"""
        self.bus.engage(self.channel, owner="material-ch%d" % self.channel)
        return self

    def clutch_off(self):
        """断开全部离合并停止电机"""
        self.bus.motor.stop()
        self.bus.release_all()
        return self

    @property
    def clutch_engaged(self):
        return self.bus.clutches[self.channel].is_engaged()

    def hold(self):
        """返回上下文管理器，期间保持本通道离合吸合。"""
        return _HoldGuard(self)

    # ------------------------------------------------------------------
    # 到位开关
    # ------------------------------------------------------------------
    @property
    def has_limit_top(self):
        return self.limit_top.installed

    @property
    def has_limit_bottom(self):
        return self.limit_bottom.installed

    @property
    def has_limit(self):
        """本通道是否安装了任意一个到位开关"""
        return self.limit_top.installed or self.limit_bottom.installed

    def limit_triggered(self, orientation=1):
        """到位开关是否被触发。

        orientation =  1 表示查"进料到位"（dianji_bottom）
        orientation = -1 表示查"退料到位"（dianji_top）
        """
        if orientation == 1:
            return self.limit_bottom.triggered()
        return self.limit_top.triggered()

    def is_jam(self):
        """两个到位开关同时触发 → 判定为卡料或机构异常。

        未安装开关时永远返回 False。
        """
        if self.limit_top.installed and self.limit_bottom.installed:
            return self.limit_top.triggered() and self.limit_bottom.triggered()
        return False

    # ------------------------------------------------------------------
    # 送料动作
    # ------------------------------------------------------------------
    def dianji_roll(self, direction=1, times_ms=200):
        """兼容老接口：本通道送料/退料 times_ms 毫秒。

        direction = 1 进料，-1 退料。
        不在 hold() 上下文里时，会自动完成"吸合 → 转 → 停 → 断开"全过程。
        """
        if self._holding:
            # 已经在 hold() 里，离合保持吸合，只做转动
            self.bus.motor.run(direction, times_ms)
            self.bus.motor.stop()
        else:
            self.bus.run(self.channel, direction, times_ms,
                         release=True,
                         owner="material-ch%d" % self.channel)
        return self

    def feed(self, times_ms=1000):
        """进料"""
        return self.dianji_roll(1, times_ms)

    def retract(self, times_ms=1000):
        """退料"""
        return self.dianji_roll(-1, times_ms)

    def stop_roll(self):
        """停止电机（不改变离合状态）。

        注意：老代码在 dianji_roll 末尾调用它做收尾，这里只负责停电机，
        离合的断开由 dianji_roll 内部的 bus.run(release=True) 保证。
        """
        self.bus.motor.stop()
        return self

    def is_one(self, duration=10, orientation=-1):
        """在 duration 秒内尝试把料拉到位。

        到位返回 True；无到位开关时直接返回 False（无法判定）。
        """
        if not self.has_limit:
            logout("通道%d 未安装到位开关，is_one() 无法判定，返回 False" % self.channel)
            return False
        deadline = time.time() + duration
        with self.hold():
            while time.time() < deadline:
                if self.limit_triggered(orientation):
                    self.bus.motor.stop()
                    return True
                # 低速推进，给开关留出响应时间
                self.bus.motor.set_direction(orientation)
                time.sleep_ms(50)
            self.bus.motor.stop()
        return False

    def __repr__(self):
        return "<material ch=%d limits(top=%s,bottom=%s) engaged=%s>" % (
            self.channel, self.limit_top.installed, self.limit_bottom.installed,
            self.clutch_engaged)


# ==========================================================================
# 四、上电自检 / 手动点动（把本文件当脚本跑时执行）
# ==========================================================================
if __name__ == "__main__":
    from hardware_config import validate, describe

    ok, problems = validate()
    logout(describe())
    if not ok:
        for item in problems:
            logout("[配置问题] " + item, is_error=True)
        raise SystemExit("硬件配置有误，请检查 hardware_config.py")

    bus_test = build_motor_bus()
    for ch in bus_test.channels:
        logout("点动通道%d：进料 800ms" % ch)
        bus_test.run(ch, direction=1, times_ms=800, owner="selftest-ch%d" % ch)
        # 每一次点动结束后都必须回到"全部断开"状态
        left = bus_test.engaged_channels()
        logout("通道%d 点动结束，仍吸合的离合: %s" % (ch, left if left else "无"))
        time.sleep_ms(300)

    logout("自检完成，冲突次数 = %d（正常应为 0）" % bus_test.conflicts)

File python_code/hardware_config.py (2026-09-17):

"""
hardware_config.py —— 硬件配置入口（板型自动选择 + 运动参数）
=============================================================

本文件是**唯一的硬件配置入口**。它分三部分：

    一、板型选择 —— 同一个固件要同时支持 ESP32-C3 和 ESP32-S3，
        引脚能力差异放在两个独立文件里：
            board_c3.py  ← C3 的引脚表 / 保留脚 / strapping
            board_s3.py  ← S3 的引脚表 / 保留脚 / strapping / 剩余可用 IO
        本文件负责"认出当前是哪块板"，然后把对应引脚表导出来，
        这样上层代码（motor_clutch / AMS_MODEL / reset_info …）
        只管 `from hardware_config import MOTOR_PIN_IN1`，一行都不用改。

    二、业务参数 —— 动作时长、离合等待、点动范围、降级模式时长…
        这些和芯片无关，改接线不用动它们。

    三、自检 —— 引脚合法性、重复占用、strapping 误用，上电就报。

--------------------------------------------------------------------------
一、板型是怎么定下来的（三条路，优先级从高到低）
--------------------------------------------------------------------------
    1. 构建时写死的 `board_select.py`：
           BOARD = "c3" | "s3" | "auto"
       tools/build_mpy.py --board s3 会生成这一行，
       所以 CI 打出来的两个固件各自"天生长在对应的板子上"。

    2. 现场覆盖文件 `board_override.py`（不进 git，可选）：
           放在板子上就能覆盖本文件里的任何引脚常量，例如
               CLUTCH_PINS = (6, 7, 10, 1)
               LED_PIN = None
       适合"手上这块板子接线和别人不一样"的情况，不用改仓库代码。

    3. 自动识别：`os.uname().machine`
           "ESP32S3 module with ESP32S3" → S3
           "ESP32C3 module with ESP32C3" → C3
       认不出来时**默认 C3**（并在自检里提示）。

--------------------------------------------------------------------------
★★★ 为什么必须有 S3 这条路（实测结论，不是拍脑袋）★★★
--------------------------------------------------------------------------
    C3 只有 400KB SRAM。本应用加载完之后空闲堆约 60KB，
    而 ESP32 的 WiFi 驱动收发数据要动态申请**连续**内存做缓冲：

        未加载应用（空闲 149KB）：65KB 的 index.html 5.7 秒发完，链路正常
        加载应用后（空闲  60KB）：第一个 TCP 分段就 OSError(113)
                                  （重传 9.4 秒后放弃，随后射频卡死，只能复位）

    表现就是"网页一直转圈/打不开"，而且加上 OTA 之后应用更大了，
    问题从"偶发"变成"必然"。S3 的可用堆大得多，这条路才走得通。

    所以：C3 是"能跑但网页很勉强"，要稳就用 S3（见 board_s3.py）。

--------------------------------------------------------------------------
二、硬件方案（两块板通用）
--------------------------------------------------------------------------
    **1 个共享直流电机 + 4 路电磁离合**

                       ┌── 离合1 ──> 料盘位1 送料轮
        共享电机 ──────┼── 离合2 ──> 料盘位2 送料轮
        (H桥 IN1/IN2)  ├── 离合3 ──> 料盘位3 送料轮
                       └── 离合4 ──> 料盘位4 送料轮

    需要哪个料盘位送料，就把该路离合吸合让送料轮与电机主轴咬合，
    然后电机正转（进料）/ 反转（退料），动作完成立刻断开离合。

    ⚠️ 硬性约束：**任何时刻最多只能有 1 路电磁离合吸合。**
       两路同时吸合会让两卷料互相拉扯 → 料线绷断、打滑。
       这条约束由 motor_clutch.FilamentMotorBus 在软件层四重强制。

--------------------------------------------------------------------------
三、离合驱动的硬件注意（**强烈建议**照做）
--------------------------------------------------------------------------
    1. 离合是感性负载，线圈两端必须反向并联续流二极管（1N4148 / 1N5819）。
    2. GPIO 只能出 20mA，**不要**直接驱动线圈，中间要加三极管
       （S8050 / 2N2222）、MOS（AO3400 / IRLZ44N）或光耦驱动板；
       三极管方案基极串 1kΩ。
    3. 4 路不要同时吸合，除了机械原因还有供电：浪涌很容易把 5V 拉塌
       导致 ESP32 复位。软件互斥同时也保护了电源。

--------------------------------------------------------------------------
四、到位开关（限位/微动开关）—— 当前未安装，接口已预留
--------------------------------------------------------------------------
    作用：now_filament() 探测当前料盘位；fileament_move() 判断是否卡料/到底。
    原理：该料盘有料时反转会把送料臂推到位触发开关，空盘反转只空转。

    现在配置为 None，程序自动进入**降级模式**：
        · 不探测当前料盘，沿用 config.json 里的 filament_current
        · 送料/退料按时间推进，时长见下面 NO_LIMIT_*（**必须实测调整**）

    装开关后把引脚填进 LIMIT_SWITCH_PINS 即可自动启用探测。
    推荐接法（一端接 GPIO、一端接 GND，内部上拉，低电平触发）：
        · C3：用 0 / 1 / 8 / 9（strapping 脚作输入是安全的）
        · S3：用 11~14（全干净，排针集中）
"""

# ==========================================================================
# 零、选板型
# ==========================================================================
# 1) 构建时写死的选择（tools/build_mpy.py --board 会生成这个文件）
try:
    from board_select import BOARD as _BUILT_BOARD
except ImportError:
    _BUILT_BOARD = "auto"


def _machine_name():
    try:
        import os

        return os.uname().machine.upper()
    except Exception:
        return ""


def _detect_board():
    """返回 "c3" 或 "s3"，以及判定依据（给自检打印用）。"""
    if _BUILT_BOARD in ("c3", "s3"):
        return _BUILT_BOARD, "构建时指定（board_select.py）"

    machine = _machine_name()
    if "S3" in machine:
        return "s3", "自动识别 os.uname().machine=%r" % machine
    if "C3" in machine:
        return "c3", "自动识别 os.uname().machine=%r" % machine
    return "c3", "认不出芯片（machine=%r），按 C3 处理" % machine


BOARD_ID, BOARD_SOURCE = _detect_board()

if BOARD_ID == "s3":
    import board_s3 as _board
else:
    import board_c3 as _board

BOARD_NAME = _board.BOARD_NAME
CHIP = _board.CHIP
GPIO_MAX = _board.GPIO_MAX
STRAPPING_PINS = _board.STRAPPING_PINS
SAFE_OUTPUT_PINS = _board.SAFE_OUTPUT_PINS
RESERVED_PINS = _board.RESERVED_PINS
SPARE_PINS = _board.SPARE_PINS
STRAPPING_SPARE_PINS = getattr(_board, "STRAPPING_SPARE_PINS", ())
RECOMMENDED_LIMIT_SWITCH_PINS = getattr(_board, "RECOMMENDED_LIMIT_SWITCH_PINS", ())
BOARD_NOTES = _board.BOARD_NOTES
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

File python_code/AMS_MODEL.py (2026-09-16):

"""
AMS_MODEL.py —— AMS 业务逻辑（换料调度）
==========================================

本文件负责：
    · 与拓竹打印机通过 MQTT 通信
    · 接收打印机的换料请求（暂停 + M73 P101）
    · 驱动"共享电机 + 4 路电磁离合"完成退料 / 进料
    · 通知打印机继续打印

--------------------------------------------------------------------------
硬件层（本版新增）
--------------------------------------------------------------------------
整机只有 **1 个共享直流电机 + 4 路电磁离合**：

    self.motor_bus      —— FilamentMotorBus，负责电机方向与离合仲裁
    self.meterial_list  —— 4 个 material 对象，分别对应物理料盘位 1~4
    self.dianji_dict    —— 打印机通道号 → material 对象的映射（由 access_list 决定）

★ 硬性约束：任何时刻最多只能有 1 路电磁离合吸合。
  这条约束由 FilamentMotorBus 在软件层强制保证：
      · 每次吸合前先无条件下发"全部断开"
      · 吸合前回读复核，发现残留立即全部断开并取消动作
      · 换料流程用 try/finally 包住，异常时也一定停电机 + 断开全部离合
      · 主循环每个周期调用 assert_single() 体检
  业务代码**不需要**自己做互斥判断，但要避免自己去写离合的 GPIO。

--------------------------------------------------------------------------
换料时序（与老版本保持一致，只是底层换了执行机构）
--------------------------------------------------------------------------
    1. 打印机进入暂停换料状态（M73 P101 + M400 U1）
    2. AMS 发 M83，切到相对挤出模式
    3. 打印机退料：G1 E-50 F200
    4. AMS 侧收料：吸合【旧】通道离合 → 电机反转 → 停 → 断开离合
    5. AMS 侧送料：吸合【新】通道离合 → 电机正转 → 停 → 断开离合
    6. 打印机进料：G1 E50 F200，同时 AMS 辅助推料一小段
    7. 记录当前料盘并持久化到 config.json
    8. 发 resume 让打印机继续打印
"""

from device_processing import material, build_motor_bus, build_materials
from bambu.bambu_mqtt import Bambu_mqtt_cliet
import time
from logout import logout
from bambu.bambu_commands import banbu_start, START_PUSH
import ujson
from bambu.bambu_commands import *
from info_load import read_json_file, write_json_file
import uasyncio as asyncio

from hardware_config import (
    CONFIG_FILE,
    RETRACT_STEPS,
    LOAD_RETRY_TIMES,
    LOAD_ASSIST_MS,
    NO_LIMIT_LOAD_MS,
    NO_LIMIT_RETRACT_MS,
    NO_LIMIT_PROBE_MS,
    JOG_TIME_MS,
    JOG_MIN_MS,
    JOG_MAX_MS,
)
from motor_clutch import ClutchConflictError, MotorBusError


# ==========================================================================
# 主循环节奏（毫秒）
# ==========================================================================
#   AMS_POLL_MS        非阻塞收包的轮询间隔。越小响应越快，200ms 足够，
#                      而且这个 await 会把 CPU 让给 Web / 状态灯任务。
#   PUSH_INTERVAL_MS   多久向打印机查询一次状态。打印机自己也会主动上报，
#                      1 秒一次就够。旧代码隐含节奏也是 ~1 次/秒。
#   RECONNECT_INTERVAL_MS  定期重建 MQTT 连接的间隔。旧代码是"每 20 轮"，
#                      而每轮都阻塞等消息，实际变成几秒断一次，非常不稳；
#                      改成 5 分钟一次。
AMS_POLL_MS = 200
PUSH_INTERVAL_MS = 1000
RECONNECT_INTERVAL_MS = 300000


class AMS(Bambu_mqtt_cliet):
    def __init__(self):
        super().__init__(mqtt_server="", DEVICE_SERIAL="", password="")   # 继承MQTT类

        # ------------------------------------------------------------------
        # 硬件层：1 个共享电机 + 4 路电磁离合
        # ------------------------------------------------------------------
        self.motor_bus = build_motor_bus()
        self.meterial_list = build_materials(self.motor_bus)

        # ------------------------------------------------------------------
        # 业务层：打印机通道号映射
        # ------------------------------------------------------------------
        self.color_list = ["red" for n in range(len(self.meterial_list))]
        self.access_list = [n + 1 for n in range(len(self.meterial_list))]  # 颜色映射通道
        # 打印机通道号 -> 物理料盘位对象
        self.dianji_dict = {key: value for key, value in zip(self.access_list, self.meterial_list)}

        self.filament_current = 0   # 当前正在用的料盘（打印机通道号，0 = 未知）
        self.now_warring = ""
        self.config_file = CONFIG_FILE

        # ------------------------------------------------------------------
        # 网页手动点动的"进退响应时间"（4 个通道统一用这一个值）
        # ------------------------------------------------------------------
        # ★ 只作用于「硬件调试」里的手动点动按钮，不影响自动换料
        #   （自动换料走 NO_LIMIT_LOAD_MS / FILAMENT_STEP_MS 那一套）。
        #   真正生效的值从 config.json 的 jog_ms 恢复，这里只是出厂默认。
        self.jog_ms = JOG_TIME_MS

        # ★ MQTT 配置刚被网页改过（需要主循环尽快用新参数重连一次）。
        #   不在请求里现场连，是因为 TLS 握手会把整个事件循环按住好几秒 ——
        #   那正是"保存 MQTT 时网页像卡死"的来源。
        self._mqtt_dirty = False

    # ======================================================================
    # 日志
    # ======================================================================
    def update_warring(self, text, is_error=False):
        if len(self.now_warring) >= 30:
            indexs = self.now_warring.find("\n")
            self.now_warring = self.now_warring[indexs:]
        self.now_warring += (text + "\n")

    # ======================================================================
    # 配置加载 / 保存
    # ======================================================================
    def auto_update_access(self, file_path=None):
        """从配置文件恢复通道映射、颜色和当前料盘"""
        file_path = file_path or self.config_file
        file_data = read_json_file(file_path)
        if not file_data:
            self.filament_current = 0
            return False

        color_list = file_data.get("color_list", None)
        if color_list:
            self.color_list = color_list

        new_data = file_data.get("access", None)
        if new_data:
            self.access_list = new_data
            self.dianji_dict = {key: value for key, value in zip(self.access_list, self.meterial_list)}

        # 恢复上次记录的当前料盘（没有到位开关时这一步很关键）
        saved = file_data.get("filament_current", 0)
        if saved:
            self.filament_current = saved
            logout("从配置恢复当前料盘: %s" % saved)

        # 恢复网页上设的「进退响应时间」
        self.jog_ms = self.clamp_jog_ms(file_data.get("jog_ms", self.jog_ms))
        logout("手动点动进退响应时间: %.1f 秒" % (self.jog_ms / 1000.0))

        self.filament_current = self.now_filament(self.filament_current)
        return bool(new_data)

    # ======================================================================
    # 手动点动的进退响应时间（4 个通道统一）
    # ======================================================================
    @staticmethod
    def clamp_jog_ms(value):
        """把用户填的时长夹到安全区间（单位**毫秒**，整数值）。

        调用方负责把"秒"换算成毫秒（见 AMS_WEB.handle_jog_set），
        这里统一按毫秒处理。宁可夹住也不能放行：
        0 毫秒没有意义（离合还没咬合就停了），几百秒会把关在机构里的料顶坏。
        """
        try:
            ms = int(float(value))
        except Exception:
            return JOG_TIME_MS
        if ms < JOG_MIN_MS:
            return JOG_MIN_MS
        if ms > JOG_MAX_MS:
            return JOG_MAX_MS
        return ms

    def set_jog_ms(self, value):
        """设置并持久化进退响应时间（返回实际生效的毫秒数）。
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

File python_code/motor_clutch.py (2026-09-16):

"""
motor_clutch.py —— 共享直流电机 + 多路电磁离合 的驱动层
========================================================

硬件拓扑：
                    ┌── 离合1 ──> 料盘位1 送料轮
     共享电机 ──────┼── 离合2 ──> 料盘位2 送料轮
     (H桥 IN1/IN2)  ├── 离合3 ──> 料盘位3 送料轮
                    └── 离合4 ──> 料盘位4 送料轮

本模块提供四个类：

    LimitSwitch        —— 到位/限位开关（微动开关、光电开关），未安装时可透明降级
    HBridgeMotor       —— H 桥两线电机（IN1/IN2），只有方向，含换向死区保护
    Clutch             —— 单路电磁离合，**不允许绕过总线直接吸合**
    FilamentMotorBus   —— 总线仲裁层，**强制保证同一时刻最多 1 路离合吸合**

============ "只能 1 路离合吸合" 是怎么被强制的 ============

这是本模块最重要的职责，做了四重保障：

  1. 物理层前置断开
     FilamentMotorBus.engage() 在吸合目标通道之前，**无条件**先把所有离合
     的引脚写成"断开"电平，再等一段时间让上一路彻底脱开，然后才吸合目标。
     也就是说，任何一次吸合动作都是从"全断开"状态出发的。

  2. 吸合前状态复核
     写完全部断开后立刻回读每一路的状态。如果发现还有残留吸合
     （比如引脚被外部代码改写、或驱动板没跟上），立即再次全部断开，
     并抛 ClutchConflictError 取消本次动作，绝不带病吸合。

  3. 直接调用拦截
     Clutch.engage() / Clutch.release() 必须经过总线仲裁；没绑定总线的
     Clutch 直接调用会抛 MotorBusError。只有总线内部能改引脚电平。

  4. 运行期体检
     FilamentMotorBus.assert_single() 可以随时调用，发现多路吸合就
     立刻停电机 + 全部断开。主循环里建议每个周期都调一次（开销极小）。

另外，所有"吸合→动作→断开"的复合操作都走 `run()` 或 `hold()`，
它们用 try/finally 保证即使中途抛异常也一定会释放离合、停止电机。
"""

from machine import Pin
import time

# ==========================================================================
# 异常类型
# ==========================================================================


class MotorBusError(Exception):
    """总线/驱动层异常基类"""


class ChannelOutOfRange(MotorBusError):
    """通道号不存在"""


class ClutchConflictError(MotorBusError):
    """检测到多于 1 路电磁离合同时吸合 —— 严重违反硬件约束"""


class MotorBusyError(MotorBusError):
    """总线正在被其它动作占用，拒绝并发切换通道"""


# ==========================================================================
# 工具类
# ==========================================================================


class NullPin:
    """未安装的外设占位对象，接口与 machine.Pin 兼容。

    作用：让上层代码（尤其是历史代码）可以无脑调用 .value()，
    不需要到处写 `if switch is not None` 判断。
    """

    __slots__ = ("_value", "id")

    def __init__(self, value=0, id=-1):
        self._value = value
        self.id = id

    def value(self, *args):
        if args:
            self._value = 1 if args[0] else 0
            return None
        return self._value

    def init(self, *args, **kwargs):
        return None

    def on(self):
        self.value(1)

    def off(self):
        self.value(0)

    def __repr__(self):
        return "<NullPin value=%d>" % self._value


class LimitSwitch:
    """到位 / 限位开关（微动开关、光电开关均可）。

    未安装时 installed 为 False，triggered() 恒返回 False，
    上层代码无需做 None 判断，探测逻辑会自动降级。
    """

    def __init__(self, pin=None, active_level=0, pull_up=True, name="limit"):
        self.name = name
        self.active_level = 1 if active_level else 0
        self.installed = pin is not None
        if self.installed:
            pull = Pin.PULL_UP if pull_up else Pin.PULL_DOWN
            self.pin = Pin(pin, Pin.IN, pull)
        else:
            # 未安装时给一个"永不触发"的替身：空闲电平与 active_level 相反
            self.pin = NullPin(1 - self.active_level, id=-1)

    def triggered(self):
        """开关是否被触发（当前是否到位）"""
        if not self.installed:
            return False
        return self.pin.value() == self.active_level

    def value(self):
        """原始电平，便于调试"""
        return self.pin.value()

    def __repr__(self):
        state = "未安装" if not self.installed else ("触发" if self.triggered() else "未触发")
        return "<LimitSwitch %s %s>" % (self.name, state)


# ==========================================================================
# 电机
# ==========================================================================


class HBridgeMotor:
    """H 桥两线直流电机驱动（IN1 / IN2）。

    方向定义（与老代码保持一致）：
        direction =  1  → 进料（正转）
        direction = -1  → 退料（反转）
        direction =  0  → 停止

    换向时会先停止、等待 dead_time_ms 再反向，避免 H 桥上下管直通
    （直通会瞬间烧毁驱动芯片），同时也减小对机械结构的冲击。
    """

    def __init__(self, pin_in1, pin_in2, dead_time_ms=30, name="motor"):
        self.name = name
        self.in1 = Pin(pin_in1, Pin.OUT)
        self.in2 = Pin(pin_in2, Pin.OUT)
        self.dead_time_ms = dead_time_ms
        self._direction = 0
        self.stop()

    @property
    def direction(self):
        return self._direction

    def stop(self):
        """立即停止（两脚同时拉低）"""
        self.in1.value(0)
        self.in2.value(0)
        self._direction = 0
        return self

    def set_direction(self, direction):
        """设置方向并立即启动，不阻塞"""
        direction = int(direction)
        if direction == 0:
            return self.stop()
        if direction not in (1, -1):
            raise ValueError("direction 只能是 1(进料) / -1(退料) / 0(停止)")
        if self._direction == direction:
            return self          # 同方向重复设置，不做无谓的停-启
        if self._direction != 0:
            # 换向：先刹车，留出死区时间
            self.stop()
            if self.dead_time_ms:
                time.sleep_ms(self.dead_time_ms)
        if direction == 1:
            self.in1.value(1)
            self.in2.value(0)
        else:
            self.in1.value(0)
            self.in2.value(1)
        self._direction = direction
        return self

    def run(self, direction=1, times_ms=200):
        """设置方向并阻塞运行 times_ms 毫秒（不自动停止）"""
        self.set_direction(direction)
        if times_ms and times_ms > 0:
            time.sleep_ms(times_ms)
        return self

    def run_then_stop(self, direction=1, times_ms=200):
        """设置方向、运行、然后停止"""
        self.run(direction, times_ms)
        return self.stop()

    def __repr__(self):
        return "<HBridgeMotor %s dir=%d>" % (self.name, self._direction)


# ==========================================================================
# 电磁离合
# ==========================================================================
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

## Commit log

2024-11-05 上传项目
2025-01-13 静态文件
2025-01-13 固件程序
2025-01-13 新建 打印件
2025-01-13 妞子开关
2025-01-13 删除文件 AMS_FINAL_V4
2025-01-13 删除文件 README.md
2025-01-13 重命名 YAO_AMS(基于YBA-AMS改进版).md 为 README.md
2025-01-13 删除文件 assets
2026-09-16 feat: 改用「1 电机 + 4 路电磁离合」方案，补齐文档与 CI
    硬件层（新增）
    - hardware_config.py: 唯一的硬件配置入口。按 ESP32-C3 实际引脚约束重排
    （原代码用的 GPIO22/23 在 C3 上不存在），避开 Flash(11-17)/USB(18,19)/
    UART(20,21)/strapping(2,8,9) 保留脚，并提供 validate() 上电自检
    - motor_clutch.py: HBridgeMotor / Clutch / LimitSwitch / FilamentMotorBus
    总线仲裁层，四重机制强制「同一时刻最多 1 路电磁离合吸合」：
    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
2026-09-16 同步本地全部修改
2026-09-16 feat(ci): 提交即自动编译，产出可一键烧录的单文件固件
    - workflow: 触发改为 push 任意分支/tag + PR(main) + 手动，取消 paths 过滤
    - 新增 firmware job：下载官方 ESP32-C3 固件，用 littlefs 2.8.0 生成
    与设备同源版本的文件系统镜像，拼接为单个 BIN（0x0 起始）
    - 新增 publish job：main 推送更新滚动 latest 预发布，v* tag 发布正式 Release
    - 新增 tools/make_firmware_bin.py 与 tools/lfs_mkfs.c（littlefs 2.8.0 宿主端工具）
    - 纳入 umqtt.simple（MIT），使单文件固件自带 MQTT 依赖
    - 修复首次启动 config.json 缺失导致的 AttributeError
    - README：一键烧录为首选方式，补充 CI/R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
    [AMS_WEB.py, make_firmware_bin.py]
2026-09-16 fix(web,wifi): 修掉网页极慢/打不开，联网改为直连不扫描 + 3 次失败转热点
    联网（network_model.py）
    - 上电自动联网不再 scan()，直接用 wifi.dat 里保存的账号密码直连，开机快 1.5~3 秒
    - 连接成功判定改为「关联上 + 拿到非 0.0.0.0 的 IP」，避免 DHCP 未完成就去连 MQTT
    - 最多尝试 3 次（WIFI_BOOT_ATTEMPTS），全部失败返回 None，由上层打开热点 AMS_WIFI
    - 密码错误 / 找不到 AP 这类硬失败立即返回，不白等满超时
    - 扫描改为按需 + 60 秒缓存；新增 当前SSID / AP 状态 / 状态文案 等查询接口
    网页性能（AMS_WEB.py + AMS_MODEL.py + bambu_mqtt.py）
    - index.html 整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
    [AMS_MODEL.py, AMS_WEB.py, bambu_mqtt.py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]
2026-09-16 fix(hw): 电机不能接 GPIO2/GPIO3（strapping 脚），并加上复位诊断
    现象：接上负载后电机一直有电流声（一会长鸣、一会间隔响），板子像在
    反复重启，Wi-Fi 能连但网页打不开。
    根因：
    1. GPIO2 / GPIO3 是 ESP32-C3 的 strapping 启动模式脚（TRM 第 7 章表
    7.2-1：复位释放后由 GPIO2、GPIO3、GPIO8、GPIO9 共同控制 Boot 模式），
    而 AT8236 的 IN1/IN2 内置下拉电阻，上电瞬间把它们拉低，
    芯片进不了正常启动模式。旧版 validate() 的 strapping 列表漏了 GPIO3。
    2. GPIO2 上本来就挂着 1kHz 的状态灯 PWM，IN1 再接到 GPIO2 上，
    电机就跟着状态灯闪 ——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
    [AMS_WEB.py, boot.py, device_processing.py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]
2026-09-16 fix(web): 页面改分块流式发送，修掉 AP 下管理页打不开的 OOM
    现象：刷完固件能连上 AMS_WIFI 热点，但管理页打不开，串口疯狂刷
    处理请求出错: memory allocation failed, allocating 36096 bytes。
    hanld_rootv2() 里 open("index.html","r").read() 把 40KB 的整份页面
    读成一个字符串，send_response 里再过一次 .encode() —— 峰值要 80KB。
    ESP32-C3 空闲堆只有几十 KB 且碎片化严重，连续 36~42KB 根本拿不到。
    更坑的是 _index_cache 没写进去，所以**每个请求都在同一处再失败一次**，
    页面永远打不开（全项目只有这一处大对象分配，且此前 gc.collect() 从未调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
    [AMS_MODEL.py, AMS_WEB.py, preview_server.py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]
2026-09-16 feat(web): 改左侧菜单 + 右侧内容与日志，修掉保存 404 / 通道不显示
    一次处理用户反馈的 5 个问题：
    1) 通道和硬件调试一直停在"加载中"
    boot() 先用 DEFAULT_CHANNELS=[1,2,3,4] 把 4 个通道和 8 个点动按钮画出来，
    不再等 /status；/status 同步瘦身（去掉体积巨大的 boot_safety.report、
    逐字段 _safe 兜底、SSID 限 12 个），中文响应改分块编码，避免真机 OOM。
    2) 连上网之后不要再显示 WiFi 配置
    菜单项标 apOnly，只有配置热点开着才出现；热点关掉时自动跳回运行状态。
    配网成功后立即关热点。
    3) MQTT 保存提示 404 且不持久化
    根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
    [AMS_WEB.py, bambu_mqtt.py, info_load.py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]
2026-09-16 fix(web,hw): 治页面卡死/点动转圈，新增进退响应时间与应用层 OTA
    用户反馈的 5 个问题，逐条落到代码上：
    1) 系统太慢、刷新打不开、要刷好几次才出页面
    - /status 彻底去掉网络 I/O：新增 mqtt_alive_cached()，只读缓存标志，
    页面每 2 秒轮询它也不会再触发 TLS ping（这是"页面假死"的根因）。
    - HTTP 改为 worker pool（WEB_WORKERS=3）并发接客，
    listen backlog 从 2 提到 LISTEN_BACKLOG=8。
    浏览器会并发开好几条连接，backlog=2 时后面的直接被 RST，
    表现就是"第一次打不开、刷几次才出来"。
    - 首字节窗口 HEAD_FIRST_BYTE_MS 从 600ms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
    [AMS_MODEL.py, AMS_WEB.py, bambu_mqtt.py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]
2026-09-16 fix(tools): 修好本地预览页的 OTA 上传（请求体被读两次导致死锁）
    用预览服务验证 OTA 页面时发现：上传 .ams 更新包永远停在
    「正在上传 xxx.ams… 请不要断电。」，几十秒后超时；
    整机 BIN 也一样。真机固件本身没问题（自测 116 项全过），是预览服务的问题。
    根因：socket 是单向流，请求体读完就没了。
    `do_POST` 一进来就无条件 `data = self._body()` 把请求体读掉当 JSON 解，
    轮到 `/ota_upload` 再调 `self._raw_body()` 时已经无数据可读，于是永远卡在
    `rfile.read(length)` 上等一个永不到来的 308KB。
    浏览器等不到响应就把连接掐掉（服务端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
    [preview_server.py]
2026-09-17 fix(boot): 刷机后热点起不来 —— WiFi 驱动必须抢在应用加载之前初始化
    现象：CI 固件（09e749b）烧好后串口报
    RuntimeError: Wifi Unknown Error 0x0101
    热点 AMS_WIFI 不出现，板子停在 REPL。
    根因（ESP32-C3 + MicroPython 1.23.0，串口实测）：
    - 0x0101 是 ESP_ERR_NO_MEM。MicroPython 的 WiFi 错误对照表只认
    0x3001~0x300E，落在外面就显示成 "Unknown Error"，非常误导。
    - esp_wifi_init() 要一次性申请约 24KB 的【连续】堆内存。
    - 原 main.py 先 `from AMS_WEB import main_task` 把整套应用加载进堆
    （约吃掉 107KB），之后 network_model.__init__ 里再建 WLAN 时，
    名义上还剩 92KB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
    [main.py]
2026-09-17 fix(wifi): 修掉热点/Web 起不来的另外两层坑
    三层问题，都是同一个根因 —— ESP32-C3 上 MicroPython 的 GC 不做压缩，
    应用一加载完堆就被切碎（空闲 64KB，但最大连续块只剩 3,584 字节），
    之后任何"要一大块连续内存"的操作都会失败，而且失败方式很坑：
    有的抛 0x0101(ESP_ERR_NO_MEM)，有的直接硬复位、连 traceback 都没有。
    1) 热点已经开着，也会被 config() 打死（新增）
    实测（热点确实 active、ifconfig 能读出 192.168.4.1、free=56,872）：
    ap.active(True) 再来一次 -> OK（已是 no-op）
    ap.ifconfig() -> 正常
    ap.config(essid=...) -> Run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
    [AMS_WEB.py, boot_resources.py, main.py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]
2026-09-17 新增 tools/serial_provision.ps1：串口直写 wifi.dat 配网
    热点 AMS_WIFI 在软件层面正常打开（active/essid/authmode/channel 全对），
    但任何客户端都搜不到它。整片 erase_flash 后只烧官方纯净固件、裸起 AP
    依然不可见，已排除应用代码与配置因素；而关掉 AP 时 STA 能扫到 14 个网、
    能连上路由器拿 IP，说明射频接收与 STA 发射都正常 —— 定位为板子射频
    发射侧（天线/PA/供电）问题，软件无解。
    在热点不可用期间，配网只能绕开它：本脚本通过串口 REPL 直接把
    "SSID;密码" 写进 wifi.dat，让板子走 STA 连路由器，之后用局域网 IP
    访问网页。密码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
2026-09-17 支持 ESP32-S3（42 针）双开发板：引脚表拆两份，编译时自动套用对应配置
    1) 引脚配置拆分
    - 新增 board_c3.py / board_s3.py，把"这块芯片哪些脚能用"从
    hardware_config.py 里独立出来；hardware_config.py 变成
    「选板型 + 业务参数 + 上电自检」，上层代码一行都不用改
    - 板型优先级：编译期 board_select.py > 现场 board_override.py >
    os.uname().machine 识别（认不出按 C3 处理并提示）
    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
2026-09-17 记录：C3 网页打不开的内存根因 + 双开发板架构与构建方式
    - 每日日志补：pm=0 与 WiFi 连续缓冲两层根因的实测数据、双板改造要点、本机环境备忘
    - 长期备忘补：双开发板架构（board_c3/board_s3/board_select/board_override 与优先级）、
    两块板的引脚差异与 S3 剩余可用 IO、两块芯片固件的分区与 SHA256、新构建命令
